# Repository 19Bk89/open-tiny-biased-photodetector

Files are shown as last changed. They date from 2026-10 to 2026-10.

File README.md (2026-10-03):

# open-tiny-simple-biased-photodetector
A compact open-source biased photodetector with a custom PCB and 3D-printed enclosure.
The photodiode is operated with a reverse bias to improve its performance for high-speed optical detection.
The goal of this project is to provide a small, affordable and reproducible photodetector that can be built, modified and improved by others.
The design is an independent project and is not affiliated with, endorsed by, or a copy of any commercial photodetector.

The detector consists of three main parts:

Custom-designed PCB – contains the photodiode, and analog signal-conditioning electronics.
3D-printed enclosure – provides mechanical protection and houses the PCB.
Connectors – provide the electrical interface for power and signal output.

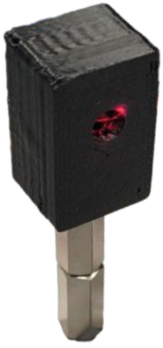
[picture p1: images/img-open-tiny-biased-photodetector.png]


# Bill of Materials
| No. | Qty. | Designator | Value | Footprint | Manufacturer Part | Supplier Part | Supplier |
| :-: | :--: | :---: | :--- | :--- | :--- | :--- | :--- |
|  1  | 1  | C1 | 100 nF | 0603 | — | - | - |
|  2  | 1  | R1 | 1 kΩ | 0603 | — | - | - |
|  3  | 1  | U1 | Photodiode | TO-18-3 | S5971 / S5972 / S5973 | - | - |
|  4  | 1  | J1 | BNC female, bulkhead | — | — | - | - |
|  5  | 1  | J2 | 4 mm banana socket, red | — | RS PRO 208-0246 | 208-0246 | RS |
|  6  | 1  | J3 | 4 mm banana socket, black | — | RS PRO 208-0245 | 208-0245 | RS |
|  7  | 2  | — | Wire, red | — | — | — | — |
|  8  | 2  | — | Wire, black | — | — | — | — |
|  9  | 2  | — | M3 heat-set insert | — | Ruthex | — | — |
|  10 | 1  | — | M4 heat-set insert | — | Ruthex | — | — |
|  11 | 1  | — | Enclosure | — | 3D-Printing | — | — |
|  12 | 2  | — | Screw M3 × 5 mm | — | — | — | — |

# Estimated Material Cost

The following prices are estimated material costs for a single detector in small quantities.

| Component | Qty. | Estimated unit price | Estimated total |
| :--- | :--: | ---: | ---: |
| C1, 100 nF, 0603 | 1  | 0.03 € | 0.03 € |
| R1, 1 kΩ, 0603 | 1  | 0.03 € | 0.03 € |
| BNC female, bulkhead | 1  | 2.50 € | 2.50 € |
| 4 mm banana socket, red | 1  | 1.50 € | 1.50 € |
| 4 mm banana socket, black | 1  | 1.50 € | 1.50 € |
| Red wire | 2  | 0.20 € | 0.40 € |
| Black wire | 2  | 0.20 € | 0.40 € |
| M3 heat-set insert | 2  | 0.20 € | 0.40 € |
| M4 heat-set insert | 1  | 0.25 € | 0.25 € |
| Enclosure, 3D-printed | 1  | 1.00 € | 1.00 € |
| M3 × 5 mm screw | 2  | 0.10 € | 0.20 € |
| **Remaining components**  | | | **8.21 €** |

## Photodiode Options
The total material cost depends mainly on the selected photodiode.
| Photodiode | Price incl. VAT | Estimated total material cost* |
| :--- | ---: | ---: |
| Hamamatsu S5971 | 10.12 € | **18.33 €** |
| Hamamatsu S5972 | 13.77 € | **21.98 €** |
| Hamamatsu S5973 | 27.85 € | **36.06 €** |
* Estimated material cost excluding PCB manufacturing and shipping.
Prices are approximate and may vary depending on supplier, order quantity and availability.
PCB manufacturing costs and shipping costs are not included.

# Development status
The current PCB revision is an updated version of the design and has not yet been experimentally tested.
The released files should therefore be considered a development revision until the updated PCB has been assembled and verified.
The previous tested design remains the reference for the currently verified hardware.
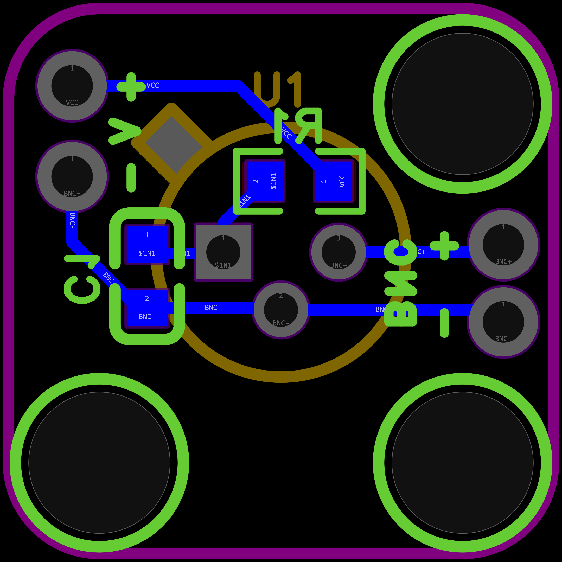
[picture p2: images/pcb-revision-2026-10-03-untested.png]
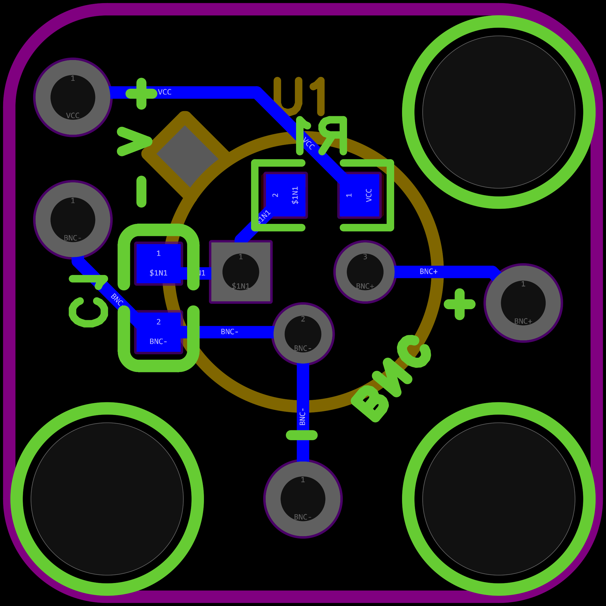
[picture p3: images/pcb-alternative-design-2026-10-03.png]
<div align="center"> <table> <tr> <td align="center"> <br> <b>Untested revision</b> </td> <td align="center"> <br> <b>Alternative design</b> </td> </tr> </table> </div>

# Operation
## Bias Supply
The photodiode is operated in reverse-bias mode.
The detector is intended to be operated from a **9 V DC supply**.
Always observe the correct supply polarity and do not exceed the specified supply voltage.

## Output Termination
For high-speed measurements, a **50 Ω termination is required**.
The recommended measurement setup is: **Photodetector → 50 Ω coaxial cable → 50 Ω oscilloscope input / 50 Ω terminator**

The 50 Ω termination provides impedance matching and minimizes reflections and ringing in the measurement setup.

When using a high-impedance input such as a 1 MΩ oscilloscope input, the output voltage will be higher, but the electrical bandwidth and transient response will differ from the 50 Ω configuration.

For the intended high-speed operation, use a **50 Ω coaxial cable and a 50 Ω terminated measurement input**.

## Measurement Considerations
* Use a 50 Ω coaxial cable for high-speed measurements.
* Use a 50 Ω termination at the receiving end.
* Keep the signal cable as short as practical when high bandwidth is required.
* A high-impedance measurement input can be used for observing low-frequency or DC signals, but it should not be considered equivalent to the 50 Ω high-speed configuration.
* The photodiode is operated under reverse bias. Do not apply forward bias to the photodiode.
* The photodiode and PCB are ESD-sensitive. Take appropriate ESD precautions when assembling or handling the detector.

## Optical Safety
The detector itself does not generate optical radiation. However, it may be used with lasers or other potentially hazardous light sources.
Follow appropriate laser and optical safety procedures when operating the detector with hazardous optical sources.

# Performance
The current PCB revision has not yet been experimentally characterized.
Therefore, no verified performance specifications are currently provided for this revision, including:

- bandwidth
- rise time
- fall time
- noise
- responsivity
- maximum optical input power
- maximum output voltage

These values will be added after the PCB has been experimentally tested.

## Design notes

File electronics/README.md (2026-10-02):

### PCB
<p align="center">
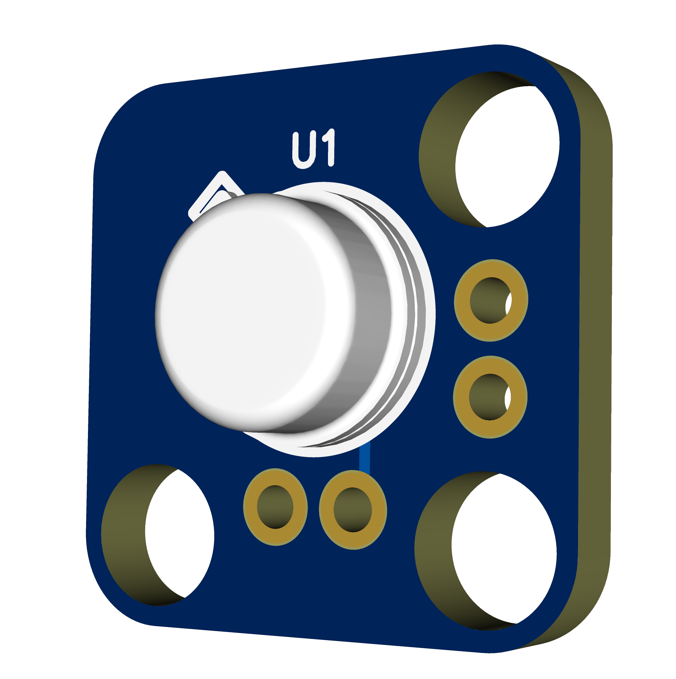
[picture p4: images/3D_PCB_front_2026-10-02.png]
3D render of the PCB front
  
  &nbsp;&nbsp;
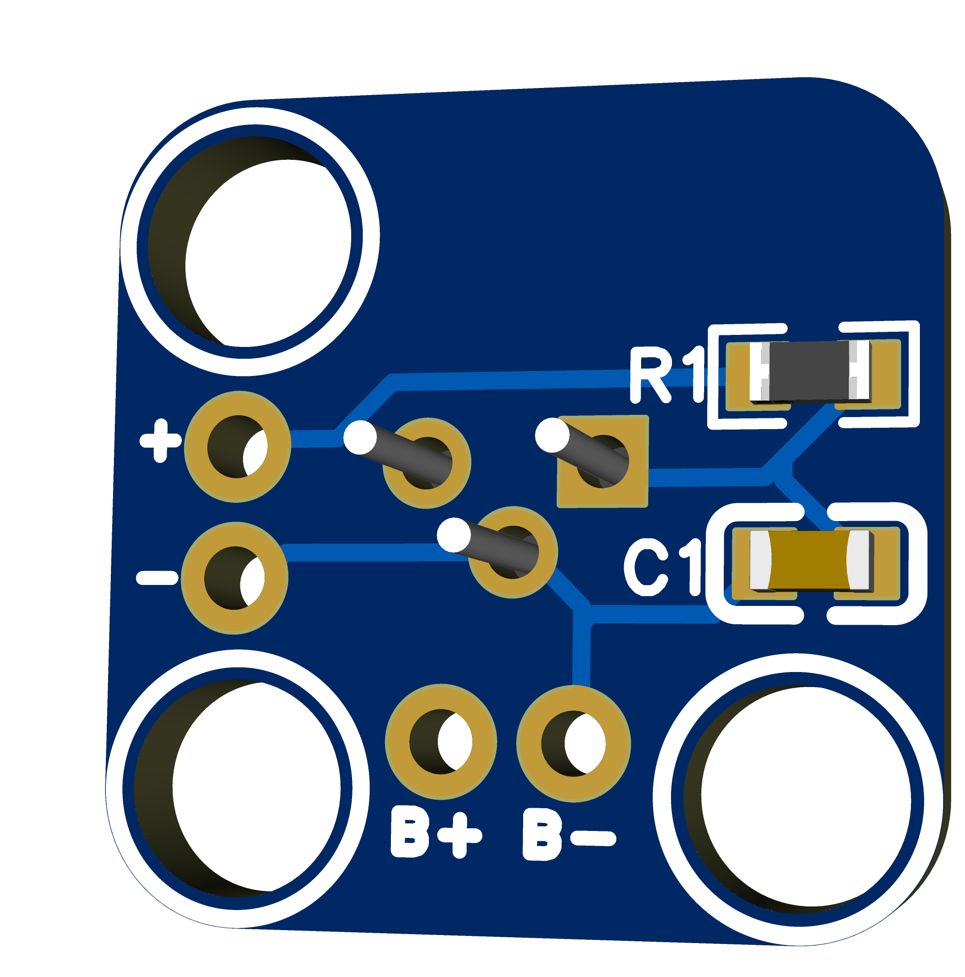
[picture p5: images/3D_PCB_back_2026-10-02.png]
3D render of the PCB back
  
</p>

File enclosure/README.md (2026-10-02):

# Enclosure
The enclosure is designed for **3D printing**. Actual dimensions and fit may vary depending on the printer, material, layer height, and slicer settings.

The enclosure is deliberately kept compact, so the fit is intentionally tight.
Depending on the printer, material, and printing tolerances, **some minor adjustment may be necessary**. If required, carefully use a **soldering iron** to slightly adjust individual areas of the printed enclosure and achieve a proper fit.
This is intentional and not a design error — the compact dimensions leave very little clearance.

<div align="center">
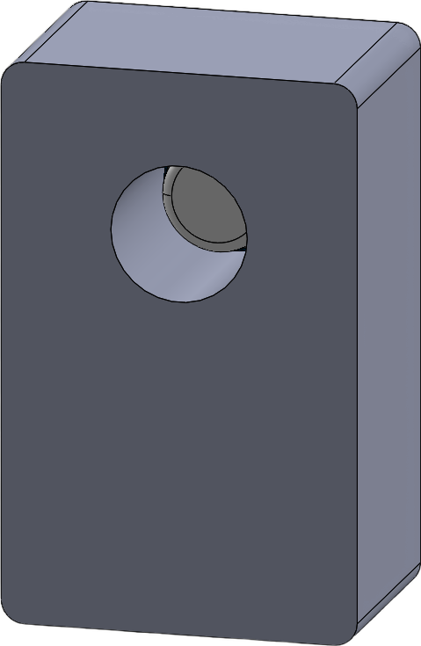
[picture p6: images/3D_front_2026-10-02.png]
  
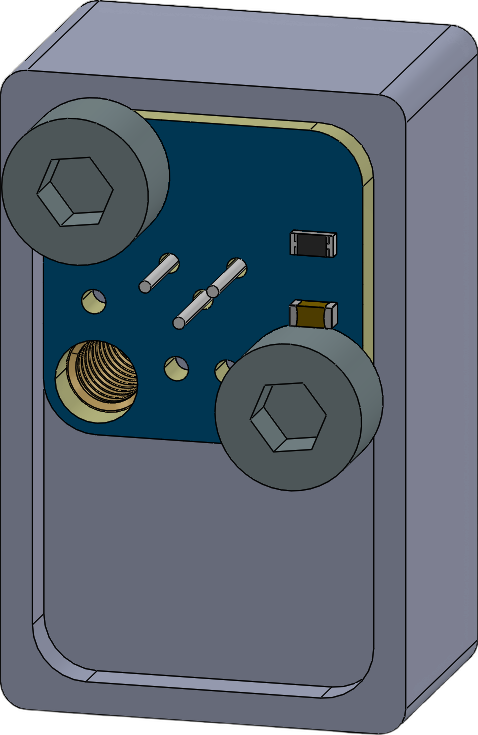
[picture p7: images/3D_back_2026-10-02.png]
  
</div>

## Assembly
The enclosure is intentionally designed to be as compact as possible. Due to the tight dimensions, some minor fitting and adjustment may be required during assembly.

### Fasteners
* **1× M4 threaded insert** — installed in the bottom of the enclosure
* **2× M3 threaded inserts** — two diagonal positions are sufficient
* **2× M3 × 5 mm screws**

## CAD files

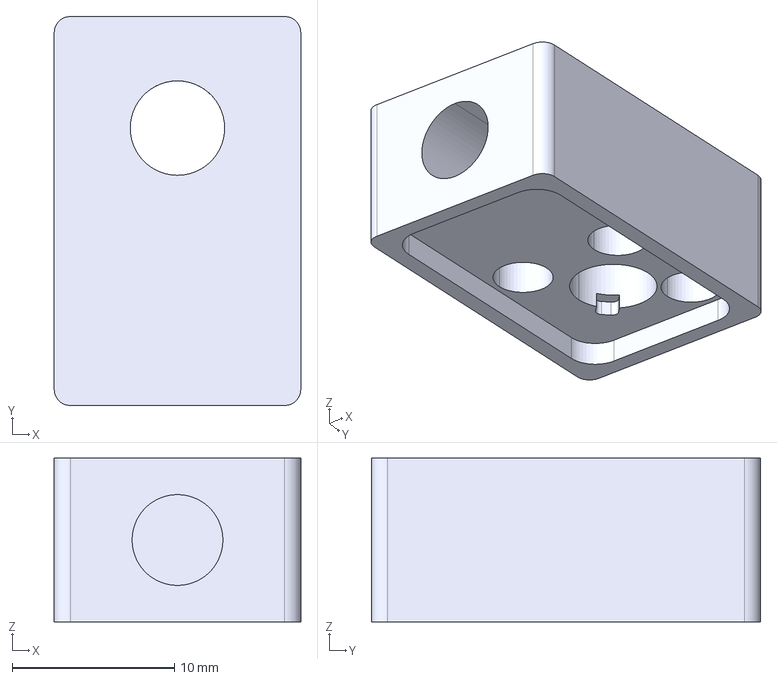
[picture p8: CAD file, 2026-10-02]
enclosure/open-tiny-biased-photodetector-enclosure.step
15.2 x 24.0 x 10.1 mm

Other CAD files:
enclosure/open-tiny-biased-photodetector-enclosure.stl

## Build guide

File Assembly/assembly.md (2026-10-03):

# Assembly
## Enclosure

### 3D Print
<div>
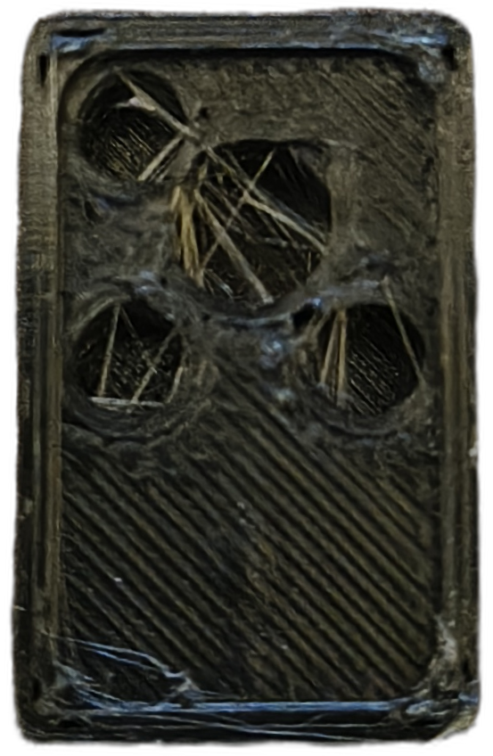
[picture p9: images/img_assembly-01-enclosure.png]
  
</div>

### Install heated inserts
<table style="border-collapse: collapse; border: none;">
  <tr>
    <td style="border: none; padding: 0 20px 0 0;">
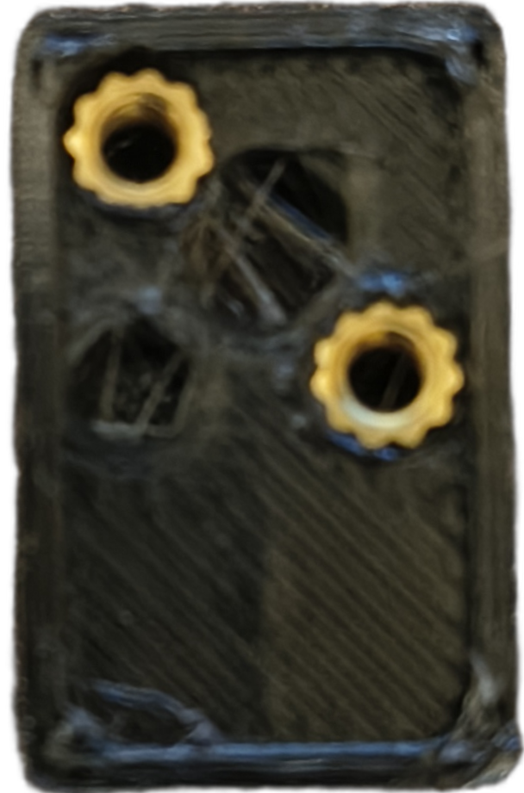
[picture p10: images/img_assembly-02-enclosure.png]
      <br>
      <b>Back</b>
    </td>
    <td style="border: none; padding: 0;">
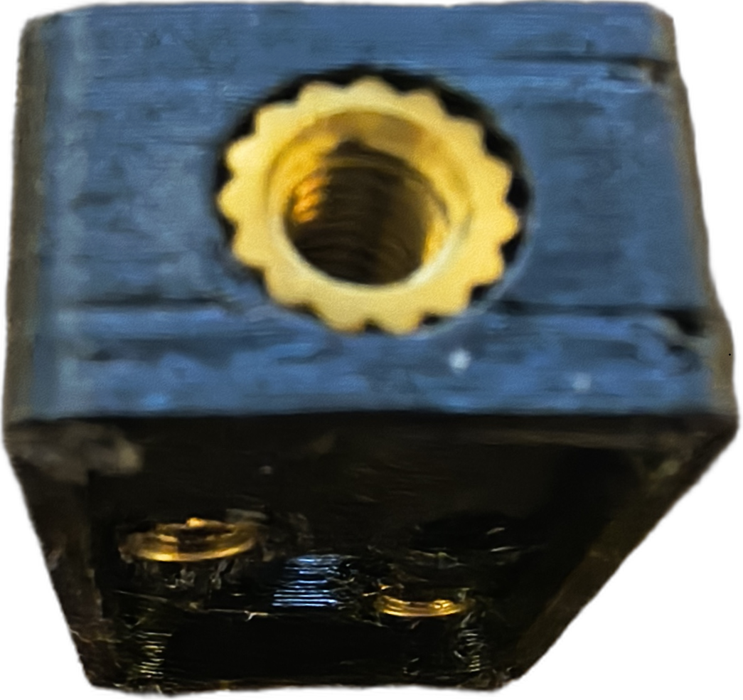
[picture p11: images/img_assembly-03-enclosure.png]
      <br>
      <b>Bottom</b>
    </td>
  </tr>
</table>

### Remove Excess Filament

## PCB
### Ordering
Use the provided Gerber files to order the PCB.
The repository also contains an **untested PCB revision with optimized terminals**.

### Assembly
Populate the PCB with all required components.

### Wiring and Connectors
Connect the wires to V+, V−, BNC+, and BNC− on the PCB.
Solder the banana sockets to V+ and V−, and the BNC connector to BNC+ and BNC−.

## Testing
### Electrical Test
### Power-On Test
### Signal Test

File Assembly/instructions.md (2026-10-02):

# Open Tiny Biased Photodetector – Assembly Instructions
This document describes the assembly, mechanical installation, electrical inspection and initial operation of the **Open Tiny Biased Photodetector**.
The current PCB revision is **untested**. The instructions below describe the intended assembly and operating procedure. Verify the circuit and PCB before applying power.

---

## 1. Required Parts
### Electronics
* 1× PCB
* 1× photodiode:
  - Hamamatsu S5971
  - Hamamatsu S5972
  - Hamamatsu S5973
* 1× C1 – 100 nF
* 1× R1 – 1 kΩ
* 1× BNC female bulkhead connector
* 1× red 4 mm banana socket
* 1× black 4 mm banana socket
* 2× red wire
* 2× black wire

### Mechanical Parts
* 1× 3D-printed enclosure
* 2× M3 heat-set inserts
* 1× M4 heat-set insert
* 2× M3 × 5 mm screws

# 2. Required Tools
The following tools are recommended:
* Soldering iron
* Solder
* Side cutters
* Wire stripper
* Multimeter
* Suitable tool for installing heat-set inserts
* 3D printer for manufacturing the enclosure
* 9 V DC laboratory power supply or suitable 9 V supply
* Oscilloscope with 50 Ω input or suitable 50 Ω terminator for high-speed measurements

A microscope or magnifying glass can be useful for inspecting the PCB solder joints.

# 3. PCB Assembly
## 3.1 Install C1
Install the **100 nF capacitor** at position **C1**.
Verify that the component is correctly positioned on the PCB.

## 3.2 Install R1
Install the **1 kΩ resistor** at position **R1**.
Verify the resistor value before soldering.

## 3.3 Install the Photodiode
Install the selected photodiode at position **U1**.
Compatible photodiodes:
* Hamamatsu S5971
* Hamamatsu S5972
* Hamamatsu S5973
The three variants use the same PCB footprint.
**Pay particular attention to the photodiode orientation and polarity.**
Do not apply forward bias to the photodiode.
Because the photodiode is ESD-sensitive, appropriate ESD precautions should be used during assembly.

## 3.4 Install the BNC Connector
Install the **BNC female bulkhead connector**
* **BNC+ – red**
* **BNC- – black**
Ensure that the connector is mechanically secure and that the center signal and ground connections are correctly soldered.

## 3.5 Install the Banana Sockets
Install the two 4 mm banana sockets:
* **V+ – red**
* **V- – black**

### Supply
Keep the wires as short as practical and route them so that they cannot interfere with the enclosure or PCB.
Before powering the detector, verify the wiring with a multimeter.

# 5. Enclosure Preparation
The enclosure is provided as a 3D-printable STL file.
Print the enclosure according to the dimensions and orientation of the supplied STL file.
The enclosure contains mounting points for heat-set inserts.

## 5.1 M3 Inserts
Install the two **M3 inserts** into the designated mounting points.
Use a suitable soldering iron or heat-set insert tool.
Heat the insert sufficiently for it to enter the plastic without excessive force.
Allow the plastic to cool before assembling the PCB.

## 5.2 M4 Insert
Install the **M4 insert** into its designated mounting point on the bottom.
Verify that the insert is seated straight and does not protrude excessively from the enclosure.

# 6. PCB Installation
Place the assembled PCB into the enclosure.
Check the following:
* PCB is seated without mechanical stress.
* Wires or parts are not trapped or pinched.

Secure the PCB using the designated mounting points and **M3 × 5 mm screws**.
Do not overtighten the screws.

# 7. Final Mechanical Inspection
Before closing the enclosure, inspect the complete assembly.
Check:
* PCB orientation
* Connector alignment
* Screw installation
* Wire routing
* Photodiode position
* No loose parts inside the enclosure

# 8. Electrical Inspection Before Power-On
**Do not connect the 9 V supply yet.**

Perform the following checks:
1. Verify the photodiode orientation.
2. Verify the polarity of V+ and V-.
3. Check for solder bridges.
4. Check for visible soldering defects.
5. Check the supply wiring for accidental shorts.
6. Verify the ground connection.
7. Verify that the BNC connector is correctly connected.
8. Check that there is no unintended connection between the supply and ground.

Use a multimeter to check for unexpected low resistance between the positive supply and ground.

# 9. Initial Power-On
The detector is intended to be operated from a: **9 V DC supply**
For the initial power-on, a **current-limited laboratory power supply** is recommended.

Connect:
* **Red → +9 V**
* **Black → GND**

Verify the polarity before switching on the supply.

After powering the detector, check for:
* abnormal current consumption
* unexpected heating
* smoke
* unusual smell
* visible damage

If anything abnormal occurs, disconnect the power immediately and inspect the PCB.

# 10. Signal Connection
The BNC connector provides the detector output.
For high-speed operation, use: **Photodetector → 50 Ω coaxial cable → 50 Ω oscilloscope input**
A suitable external **50 Ω terminator** may also be used if the oscilloscope does not provide a selectable 50 Ω input.

## 10.1 50 Ω Termination
For the intended high-speed measurement configuration, a **50 Ω termination is required**.
The 50 Ω termination provides impedance matching between the detector output, coaxial cable and measurement input.
This minimizes signal reflections and ringing and provides the intended electrical measurement conditions.
Use a **50 Ω coaxial cable** and keep the cable as short as practical when high bandwidth is required.

## 10.2 High-Impedance Measurement
A 1 MΩ oscilloscope input can be used for low-frequency or DC measurements.
However, this is **not equivalent to the intended 50 Ω high-speed configuration**.
With a high-impedance input, the measured output voltage can be higher, while the bandwidth and transient response will differ.

# 11. Operating Precautions
### Reverse Bias
The photodiode is operated in **reverse bias**.
**Do not apply forward bias to the photodiode.**

### ESD
The photodiode and electronic circuitry are ESD-sensitive.
Use appropriate ESD precautions during:
* PCB assembly
* photodiode installation
* troubleshooting
* modification
* handling of the assembled detector

### Supply Voltage
The intended supply voltage is:
**9 V DC**
Do not exceed the specified supply voltage.
Always verify supply polarity before connecting the detector.

### Optical Safety
The detector does not generate optical radiation itself.
However, it may be used with lasers or other potentially hazardous optical sources.
Follow appropriate laser and optical safety procedures when using hazardous light sources.

# 12. Troubleshooting
## No Output Signal
Check:
1. 9 V supply voltage
2. Supply polarity
3. Ground connection
4. Photodiode orientation
5. BNC connection
6. Oscilloscope input configuration
7. 50 Ω termination
8. Optical alignment and illumination
For high-speed measurements, verify that the oscilloscope input is configured for **50 Ω**.

## Unexpectedly High Output Voltage
Check whether the oscilloscope is configured for **1 MΩ** instead of 50 Ω.
The measurement conditions are different and the output voltage can therefore be higher.

## Excessive Ringing
Check:
* 50 Ω termination
* coaxial cable impedance
* cable length
* oscilloscope input configuration
* connector quality

For high-speed operation, use a short **50 Ω coaxial connection** and a properly terminated 50 Ω input.

# 14. Related Project Files
The project repository contains the files required to reproduce and modify the detector.

Typical files include:
* **EasyEDA Pro project** – editable PCB and schematic design
* **Gerber files** – PCB manufacturing files
* **STEP file** – 3D CAD assembly
* **STL files** – 3D-printable mechanical parts
* **Images** – project and assembly documentation

Always use the files belonging to the same PCB revision when manufacturing the hardware.

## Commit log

2026-10-02 Revise BOM with new components and details
    Updated the Bill of Materials with additional components and revised values.
2026-10-02 Update README with PCB images
    Added images of the PCB front and back to the README.
2026-10-02 Add PCB images to README
    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
2026-10-02 Update README with Bill of Materials and photodiode options
    Added a Bill of Materials and alternatives for photodiodes to the README.
2026-10-02 Update PCB images alignment and width in README
    Adjusted image widths for PCB renderings in README.
2026-10-02 Enhance README with BOM and alternatives
    Added Bill of Materials and photodiode alternatives sections to the README.
2026-10-02 Update screw specification in README.md
2026-10-02 Update README with assembly and fitting instructions
    Added detailed assembly instructions and fitting notes for the enclosure.
2026-10-02 Revise README for enclosure fitting and printing info
    Updated the README to clarify fitting adjustments and 3D printing details.
2026-10-02 Update README with PCB revision image and status
    Added an image of the PCB revision and clarified testing status.
2026-10-02 Update PCB revision status in README
    Clarified the status of the PCB revision in the README.
2026-10-03 Update section title and table styles in assembly.md
